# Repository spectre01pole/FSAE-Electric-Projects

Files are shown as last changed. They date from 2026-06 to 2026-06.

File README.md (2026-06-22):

# FSAE Electric Projects

Projects developed as part of Formula Student Electric vehicle development.

## Developed Circuit Boards

### Tractive System Active Light (TSAL)
- Designed and tested the TSAL board.
- Used to indicate the status of the tractive system according to Formula Student regulations.

### Voltage Indicator Board
- Designed circuitry for monitoring and indicating system voltage levels.
- Ensures safe operation and easy diagnostics.

### Brake System Plausibility Device (BSPD)
- Developed the BSPD circuit for safety compliance.
- Detects faults and disconnects power when necessary.

### Ready-To-Drive Sound Board (RTDS)
- Designed the circuit responsible for generating the Ready-To-Drive sound.
- Provides audible indication before vehicle movement.

## Skills Applied
- Analog Circuit Design
- PCB Design
- Schematic Capture
- Component Selection
- Testing and Debugging
- Electrical Safety Systems
- Formula Student EV Regulations

These projects were developed during my involvement with the Formula Student Electric team.

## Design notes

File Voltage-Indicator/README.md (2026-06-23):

# Voltage Indicator Board

## Overview

The Voltage Indicator Board is designed to provide visual indication of electrical system voltage conditions, supporting system monitoring and electrical safety awareness.

## Project Scope

This project focused on the design of the voltage indicator circuitry and PCB layout for Formula Student Electric applications.

## Responsibilities

- Circuit design
- Voltage indication circuitry development
- Component selection
- Schematic capture
- PCB layout design
- Design documentation

## Skills Demonstrated

- Analog Electronics
- PCB Design
- Voltage Monitoring Systems
- Schematic Design
- Hardware Documentation

## Current Status

Design phase completed. Manufacturing, assembly, and vehicle-level testing have not yet been performed.

## Project Context

Developed as part of Formula Student Electric vehicle development.

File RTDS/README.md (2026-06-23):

# Ready-To-Drive Sound System (RTDS)

## Overview

The Ready-To-Drive Sound System (RTDS) is a safety subsystem that generates an audible warning signal before vehicle movement, alerting nearby personnel that the vehicle is ready for operation.

## Project Scope

This project focused on the design of the RTDS circuit and PCB layout for use in a Formula Student Electric vehicle.

## Responsibilities

- Circuit design
- Audio generation circuitry development
- Component selection
- Schematic capture
- PCB layout design
- Design documentation

## Skills Demonstrated

- Electronic Circuit Design
- PCB Design
- Audio Signal Generation
- Component Selection
- Safety System Development

## Current Status

Design phase completed. Manufacturing, assembly, and vehicle-level testing have not yet been performed.

## Project Context

Developed as part of Formula Student Electric vehicle development.

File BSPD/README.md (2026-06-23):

# Brake System Plausibility Device (BSPD)

## Overview

The Brake System Plausibility Device (BSPD) is a safety subsystem used in Formula Student Electric vehicles to detect implausible driving conditions, such as simultaneous braking and acceleration requests, and initiate protective actions when required.

## Project Scope

This project focused on the design of the BSPD circuit and PCB layout to support Formula Student Electric safety requirements.

## Responsibilities

- Circuit design
- Signal monitoring circuitry development
- Component selection
- Schematic capture
- PCB layout design
- Design documentation

## Skills Demonstrated

- Analog Electronics
- Signal Conditioning
- PCB Design
- Safety System Design
- Hardware Documentation

## Current Status

Design phase completed. Manufacturing, assembly, and vehicle-level testing have not yet been performed.

## Project Context

Developed as part of Formula Student Electric vehicle development.

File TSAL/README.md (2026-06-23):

# Tractive System Active Light (TSAL)

## Overview

The Tractive System Active Light (TSAL) is a safety-critical subsystem used in Formula Student Electric vehicles to indicate the status of the tractive system and provide a visual indication of high-voltage activity.

## Project Scope

This project focused on the design of the TSAL circuit and PCB layout in accordance with Formula Student Electric requirements.

## Responsibilities

- Circuit design
- Component selection
- Schematic capture
- PCB layout design
- Design documentation

## Skills Demonstrated

- Analog Electronics
- PCB Design
- Schematic Design
- Component Selection
- Safety-Critical System Design

## Current Status

Design phase completed. Manufacturing, assembly, and vehicle-level testing have not yet been performed.

## Project Context

Developed as part of Formula Student Electric vehicle development.

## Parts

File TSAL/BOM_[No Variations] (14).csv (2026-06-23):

Line # | Name | Description | Designator | Revision ID | Revision State | Revision Status | Quantity | Manufacturer 1 | Manufacturer Part Number 1 | Manufacturer Lifecycle 1 | Supplier 1 | Supplier Part Number 1 | Supplier Unit Price 1 | Supplier Subtotal 1
 | LM2903BIDR | 36V JI.3 DUAL COMPARATOR | UGrnn, URd | CMP-04896-000007-1 | New From Design | Up to date | 2 | Texas Instruments | LM2903BIDR | Volume Production | DigiKey | 296-LM2903BIDRCT-ND | 0.26 | 0.52
 | CRCW08051K00JNEC | RES Thick Film, 1kΩ, 5%, 0.125W, 200ppm/°C, 0805 | 1K_1, 1K_2 | CMP-02407-005778-1 | New From Design | Up to date | 2 | Vishay | CRCW08051K00JNEC | Volume Production | DigiKey | 541-CRCW08051K00JNECCT-ND | 0.1 | 0.2
 | MCU08050D1004BP500 | RES 1.05K OHM 0.5% 1/5W 0805 | 1M_1, 1M_2 | CMP-02407-001361-1 | New From Design | Up to date | 2 | Vishay | MCU08050D1004BP500 | Volume Production | Mouser | 594-MCU08050D1004BP5 | 0.44 | 0.88
 | Capacitor 1µF +/-20% 10V 0402 | Chip Capacitor, 1µF +/-20%, 10V, 0402, Thickness 0.6 mm | 1uF_1, 1uF_2 | CMP-001-00063-3 | Draft | Up to date | 2 | Yageo Group | CC0402KRX5R6BB105 | Volume Production | Arrow Electronics | CC0402KRX5R6BB105 | 0.0118 | 118
 | 2K2 5% 0402(1005) | 2K2 0.063W 5% 0402 (1005 Metric) SMD | 2.2K_1, 2.2K_3 | CMP-1011-00082-1 | Released | Up to date | 2 | Yageo Group | RC0402JR-072K2L | Volume Production | Arrow Electronics | RC0402JR-072K2L | 0.0007 | 7
 | BZD27C5V1P-E3-08 | DIODE ZENER 5.1V 800MW DO219AB | 5.1V_ZD, D_4 | CMP-02541-000027-1 | New From Design | Up to date | 2 | Vishay | BZD27C5V1P-E3-08 | Volume Production | Arrow Electronics | BZD27C5V1P-E3-08 | 0.6772 | 1.3544
 | TNPW121010K0BEEN |  | 10K__9, 10K_1, 10K_2, 10K_3, 10K_3r, 10K_4, 10K_5, 10K_6, 10K_7, 10K_10, 10K_11, 10K_12, 10K_13, 10K_14, 10K_i3, 10K_rrr | CMP-2005-00857-1 | Released | Up to date | 16 | Vishay | TNPW121010K0BEEN | Volume Production | Mouser | 71-TNPW121010K0BEEN | 1.48 | 23.68
 | LM7805CT | Positive Voltage Regulator, 5 V, 1 A, -40 to 125 degC, 3-Pin TO-220, RoHS, Tube | 12V_5V_REG | CMP-2000-04938-1 | Released | Up to date | 1 | onsemi | LM7805CT | Obsolete
 | THN 20-1212 | THN 20-1212 Module DC-DC 12VIN 1-OUT 12V 1.67A 20W 6-Pin | 12V_12V_DC-DC | CMP-01539-55433698-1 | New From Design | Up to date | 1 | Traco Power | THN 20-1212 | Volume Production | DigiKey | THN20-1212-ND | 46.58 | 46.58
 | CRCW121822K0FKEK | RES Thick Film, 22kΩ, 1%, 1W, 100ppm/°C, 1218 | 22K_2 | CMP-1016-00638-2 | Unknown server | Up to date | 1 | Vishay | CRCW121822K0FKEK | Volume Production | Mouser | 71-CRCW121822K0FKEK | 0.6 | 0.6
 | 27K 1% 2010(5025) | 27K 0.75W 1% 2010 (5025 Metric) SMD | 27K_1 | CMP-1017-00670-1 | Released | Up to date | 1 | Vishay | CRCW201027K0FKTF | Volume Production | DigiKey | CRCW201027K0FKTF-ND | 0.09848 | 393.92
 | 4K7 5% 1210(3225) | 4K7 0.5W 5% 1210 (3225 Metric) SMD | 47K_n | CMP-1015-00090-1 | Released | Up to date | 1 | Vishay | CRCW12104K70JNEA | Volume Production | Arrow Electronics | CRCW12104K70JNEA | 0.0085 | 0.0085
 | 56K 5% 0805(2012) | 56K 0.125W 5% 0805 (2012 Metric) SMD | 56K_1 | CMP-1013-00116-1 | Released | Up to date | 1 | Vishay | CRCW080556K0JNEA | Volume Production | Arrow Electronics | CRCW080556K0JNEA | 0.001 | 0.001
 | CRCW121082K0FKEA | RES SMD 205K OHM 1% 1/2W 2203 | 82K_1, 82K_2 | CMP-1015-00726-2 | Unknown server | Up to date | 2 | Yageo Group | RC1210FR-0782KL | Volume Production | Mouser | 603-RC1210FR-0782KL | 0.13 | 0.26
 | TNPW0805100KDEEA |  | 100K_1, 100K_2, 100K_3, RA_100K, RB_100K | CMP-2001-04708-1 | Released | Up to date | 5 | Vishay | TNPW0805100KDEEA | Volume Production | DigiKey | 541-3911-1-ND | 0.14 | 0.7
 | C0805C104K5RACTU | CAP CER 0.1UF 50V X7R 0805 | 100nF_1, 100nF_2, 100nF_3, 100nF_4, 100nF_6, 100nF_7, 100nF_8, 100nF_9, 100nF_10, 100nF_11 | CMP-2007-00279-2 | Unknown server | Up to date | 10 | Yageo Group | C0805C104K5RACTU | Volume Production | Conrad | 3523445 | 0.01142 | 0.11424
 | Capacitor 0.1 uF +/- 5% 16 V 0402 | Chip Capacitor, 0.1 uF, +/- 5%, 16 V, 0402 (1005 Metric) | 100nF_13, 100nF_14 | CMP-001-00001-6 | Draft | Up to date | 2 | Murata | GRM155R71C104JA88D | Not Recommended for New Design | DigiKey | 490-6327-6-ND | 0.1 | 0.2
 | Capacitor 330µF +/-20% 6.3V D3 | Molded Tantalum Polymer Capacitor, 330 uF, +/- 20%, 6.3 V, -55 to 105 degC, 2-Pin SMD, RoHS, Tape and Reel | 330uF | CMP-001-00058-3 | Draft | Up to date | 1 | Panasonic | 6TPF330M9L | Volume Production | DigiKey | P16258CT-ND | 2.98 | 2.98
 | NE555DR | IC OSC SGL TIMER 100KHZ 8-SOIC | 555_1 | CMP-1685-00007-2 | Unknown server | Up to date | 1 | Texas Instruments | NE555DR | Volume Production | Arrow Electronics | NE555DR | 0.2709 | 0.2709
 | SN74LVC2G08IDCTRQ1 | Automotive Catalog Dual 2-Input Positive-AND Gate, DCT0008A, LARGE T&R | AND_1, AND_2, AND_PWR_1, AND_PWR_IC, ANDA, ANDB | CMP-0859-00543-3 | Released | Up to date | 6 | Texas Instruments | SN74LVC2G08IDCTRQ1 | Volume Production | Arrow Electronics | SN74LVC2G08IDCTRQ1 | 0.5911 | 3.5466
 | JANTX2N2222AUB/TR | JANTX2N2222AUB/TR Trans Gp Bjt NPN 50V 0.8A 3-PIN Ub T/r | BJT_1 | CMP-00252-101463705-1 | New From Design | Up to date | 1 | Microchip | JANTX2N2222AUB/TR | Volume Production | Avnet | JANTX2N2222AUB/TR | 5.7232 | 5.7232
 | CAP_2.2uF-10V-10%-0603 | 2.2µF ±10% 16V Ceramic Capacitor X5R 0603 (1608 Metric) | C_2.2uF | CMP-001-00120-1 | Draft | Up to date | 1 | Yageo Group | C0603C225K4PACTU | Volume Production | Arrow Electronics | C0603C225K4PACTU | 0.0174 | 69.6
 | 691213710003 | 213 Series 5MM Pitch Straight, Pcb Terminal Block, Through Hole, 3 Way | CMD_CONN, FB_CONN, GLVconnect, SCSnDASHind | CMP-1502-02527-3 | Released | Up to date | 4 | Wurth Elektronik | 691213710003 | Volume Production | DigiKey | 732-2039-ND | 1.43 | 5.72
 | 39-29-4069 | 39-29-4069 Conn Power HDR 6 POS 4.2mm Solder RA Thru-Hole 6 Terminal 1 Port Mini-Fit Jr™ Bag | Con B, conn A, TSconnec | CMP-00257-06821913-1 | New From Design | Up to date | 3 | Molex | 39-29-4069 | Volume Production | Arrow Electronics | 0039294069 | 3.6752 | 11.0256
 | 1N4148 | DIODE GEN PURP 100V 200MA DO35 | D2 | CMP-07163-000046-1 | New From Design | Up to date | 1 | onsemi | 1N4148 | Volume Production | Arrow Electronics | 1N4148 | 0.0045 | 0.0045
 | 1N4007 | Rectifier diode 1000 V 1 A DO-41, , | drec | CMP-123542-000001-1 | New From Design | Up to date | 1 | Diotec | 1N4007 | Volume Production | Conrad | 162272 | 0.03427 | 0.03427
 | 2N7002H6327XTSA2 | MOSFET N-CH 60V 0.3A SOT23 | M1, M2, M4 | CMP-32901-000180-1 | New From Design | Up to date | 3 | Infineon | 2N7002H6327XTSA2 | Volume Production | Arrow Electronics | 2N7002H6327XTSA2 | 0.0398 | 119.4
 | IRLML6402TRPBF | MOSFET P-CH 20V 3.7A SOT-23 | M3 | CMP-32901-000130-1 | New From Design | Up to date | 1 | Infineon | IRLML6402TRPBF | End of Life | Conrad | 162833 | 0.0914 | 0.0914
 | 9775036360R | WA-SMSR SMT Steel Spacer, Reverse M3 non Stop | MP1, MP2, MP3, MP4 | CMP-03913-78872569-2 | New From Design | Up to date | 4 | Wurth Elektronik | 9775036360R | Volume Production | DigiKey | 732-10913-1-ND | 1.09 | 4.36
 | CD4011BF3A | CMOS Quad 2-Input NAND Gate, J0014A, TUBE | NAND_PWR_IC, NOT_A, NOT_B, NOT_C, NOT_D | CMP-1627-00341-2 | Released | Up to date | 5 | Texas Instruments | CD4011BF3A | Volume Production | Arrow Electronics | CD4011BF3A | 18.53 | 685.61
 | PC817X1J000F | OPTOISOLATOR 5KV TRANS 4DIP | OP1_1, OPT_2 | CMP-65434-000003-1 | New From Design | Up to date | 2 | Sharp | PC817X1J000F | Obsolete
 | CD4071BPWR | CMOS Quad 2-Input OR Gate, PW0014A, LARGE T&R | OR_PWR_IC, ORA, ORB, ORC, ORRD | CMP-1573-00201-3 | Released | Up to date | 5 | Texas Instruments | CD4071BPWR | Not Recommended for New Design | DigiKey | 296-24349-1-ND | 0.8 | 4
 | MC14044BDG | MC14044BDG 4044 Tube 4000B ACTIVE (Last Updated: 5days ago) latch circuit 350ns 8.8mA 8.8mA 175ns 1.5mm | SR_Ltch | CMP-00278-00853159-1 | New From Design | Up to date | 1 | onsemi | MC14044BDG | Volume Production | Arrow Electronics | MC14044BDG | 0.3195 | 15.336
 | SN74LV86ATPWRG4Q1 | Automotive Catalog Quadruple 2-Input Exclusive-OR Gates, PW0014A, LARGE T&R | XOR_PWR_IC, XORA, XORB, XORC, XORD | CMP-0778-00153-3 | Released | Up to date | 5 | Texas Instruments | SN74LV86ATPWRG4Q1 | Volume Production | DigiKey | 296-SN74LV86ATPWRG4Q1CT-ND | 0.8 | 4

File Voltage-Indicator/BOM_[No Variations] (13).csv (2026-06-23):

Line # | Name | Description | Designator | Revision ID | Revision Status | Quantity | Manufacturer 1 | Manufacturer Part Number 1 | Manufacturer Lifecycle 1 | Supplier 1 | Supplier Part Number 1 | Supplier Unit Price 1 | Supplier Subtotal 1
 | CRCW08051K00JNEC | RES Thick Film, 1kΩ, 5%, 0.125W, 200ppm/°C, 0805 | 1K_1 | CMP-02407-005778-1 | Up to date | 1 | Vishay | CRCW08051K00JNEC | Volume Production | Mouser | 71-CRCW08051K00JNEC | 0.1 | 0.1
 | MCU08050D1004BP500 | RES 1.05K OHM 0.5% 1/5W 0805 | 1M_1 | CMP-02407-001361-1 | Up to date | 1 | Vishay | MCU08050D1004BP500 | Volume Production
 | 4K7 5% 1210(3225) | 4K7 0.5W 5% 1210 (3225 Metric) SMD | 4.7K | CMP-1015-00090-1 | Up to date | 1 | Vishay | CRCW12104K70JNEA | Volume Production | Arrow Electronics | CRCW12104K70JNEA | 0.0085 | 0.0085
 | BZD27C5V1P-E3-08 | DIODE ZENER 5.1V 800MW DO219AB | 5.1V_ZD | CMP-02541-000027-1 | Up to date | 1 | Vishay | BZD27C5V1P-E3-08 | Volume Production | Arrow Electronics | BZD27C5V1P-E3-08 | 0.6772 | 0.6772
 | TNPW121010K0BEEN |  | 10K_1, 10K_2, 10K_3 | CMP-2005-00857-1 | Up to date | 3 | Vishay | TNPW121010K0BEEN | Volume Production | Mouser | 71-TNPW121010K0BEEN | 1.78 | 5.34
 | 45K3 1% 2512(6432) | 45K3 1W 1% 2512 (6432 Metric) SMD | 45.3K | CMP-1018-00697-1 | Up to date | 1 | Vishay | CRCW251245K3FKEG | Volume Production | Mouser | 71-CRCW251245K3FKEG | 0.42 | 0.42
 | CRCW121082K0FKEA | RES SMD 205K OHM 1% 1/2W 2203 | 82K_1 | CMP-1015-00726-2 | Up to date | 1 | Yageo Group | RC1210FR-0782KL | Volume Production | Mouser | 603-RC1210FR-0782KL | 0.13 | 0.13
 | TNPW0805100KDEEA |  | 100K_1, 100K_2 | CMP-2001-04708-1 | Up to date | 2 | Vishay | TNPW0805100KDEEA | Volume Production | Mouser | 71-TNPW0805100KDEEA | 0.14 | 0.28
 | C0805C104K5RACTU | CAP CER 0.1UF 50V X7R 0805 | 100nF_1, 100nF_2 | CMP-2007-00279-2 | Up to date | 2 | Yageo Group | C0805C104K5RACTU | Volume Production | RS (Formerly Allied Electronics) | C0805C104K5RACTU | 0.02 | 0.04
 | 220R 1% 2010(5025) | 220R 0.75W 1% 2010 (5025 Metric) SMD | 220Ohm | CMP-1017-00433-1 | Up to date | 1 | Vishay | CRCW2010220RFKEF | Volume Production | Mouser | 71-CRCW2010220RFKEF | 0.3 | 0.3
 | LM2903BIDR | 36V JI.3 DUAL COMPARATOR | CompUHVin | CMP-04896-000007-1 | Up to date | 1 | Texas Instruments | LM2903BIDR | Volume Production | Mouser | 595-LM2903BIDR | 0.26 | 0.26
 | 2N7002H6327XTSA2 | MOSFET N-CH 60V 0.3A SOT23 | M2 | CMP-32901-000180-1 | Up to date | 1 | Infineon | 2N7002H6327XTSA2 | Volume Production | Newark | 2N7002H6327XTSA2 | 0.292 | 0.292
 | 2N3904BU | NPN General-Purpose Amplifier, 40 V VCEO, 0.2 A, -55 to 150 degC, 2-Pin TO-92, RoHS, Bulk | QP1 | CMP-2000-04944-1 | Up to date | 1 | onsemi | 2N3904BU | Volume Production | Avnet | 2N3904BU | 0.18551 | 0.18551
 | BC557BTF | BC557BTF Small Signal Bipolar Transistor, 0.1A I(C), 45V V(BR)CEO, 1-Element, PNP, Silicon, TO-92 | QP2 | CMP-00278-84408945-1 | Up to date | 1 | onsemi | BC557BTF | Volume Production | Mouser | 512-BC557BTF | 0.28 | 0.28
 | Resistor 1K +/-5 % 0402 63 mW | Chip Resistor, 1 kOhms, +/-5 %, 63 mW, -55 to 155 degC, 0402 | 1K | CMP-009-00157-3 | Up to date | 1 | Bourns | CR0402-JW-102GLF | Volume Production | Arrow Electronics | CR0402-JW-102GLF | 0.0014 | 112
 | 691213710003 | 213 Series 5MM Pitch Straight, Pcb Terminal Block, Through Hole, 3 Way | HVbuckLV connect, TSconnect | CMP-1502-02527-3 | Up to date | 2 | Wurth Elektronik | 691213710003 | Volume Production | Mouser | 710-691213710003 | 1.5 | 3
 | 39-29-4069 | 39-29-4069 Conn Power HDR 6 POS 4.2mm Solder RA Thru-Hole 6 Terminal 1 Port Mini-Fit Jr™ Bag | REDconnect | CMP-00257-06821913-1 | Up to date | 1 | Molex | 39-29-4069 | Volume Production | Arrow Electronics | 0039294069 | 3.6752 | 3.6752

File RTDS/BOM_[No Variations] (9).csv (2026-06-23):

Line # | Name | Description | Designator | Revision ID | Revision Status | Quantity | Manufacturer 1 | Manufacturer Part Number 1 | Manufacturer Lifecycle 1 | Supplier 1 | Supplier Part Number 1 | Supplier Unit Price 1 | Supplier Subtotal 1
 | Resistor 1K +/-5 % 0402 63 mW | Chip Resistor, 1 kOhms, +/-5 %, 63 mW, -55 to 155 degC, 0402 | 1K_base | CMP-009-00157-3 | Up to date | 1 | Vishay | CRCW04021K00JNED | Volume Production | Newark | CRCW04021K00JNED | 0.002 | 0.002
 | Capacitor 1µF +/-20% 10V 0402 | Chip Capacitor, 1µF +/-20%, 10V, 0402, Thickness 0.6 mm | 1uF_conv | CMP-001-00063-3 | Up to date | 1 | Yageo Group | CC0402KRX5R6BB105 | Volume Production | Mouser | 603-CC402KRX5R6BB105 | 0.11 | 0.11
 | 4K7 5% 1210(3225) | 4K7 0.5W 5% 1210 (3225 Metric) SMD | 4.7k | CMP-1015-00090-1 | Up to date | 1 | Vishay | CRCW12104K70JNEA | Volume Production | Arrow Electronics | CRCW12104K70JNEA | 0.0085 | 0.0085
 | TNPW040210K0DEED |  | 10K, 10K_2 | CMP-2002-01682-1 | Up to date | 2 | Vishay | TNPW040210K0DEED | Volume Production
 | Capacitor 0.1 uF +/- 5% 16 V 0402 | Chip Capacitor, 0.1 uF, +/- 5%, 16 V, 0402 (1005 Metric) | 100nF, 100nF_2 | CMP-001-00001-6 | Up to date | 2 | Murata | GRM155R71C104JA88D | Not Recommended for New Design | DigiKey | 490-6327-1-ND | 0.1 | 0.2
 | Capacitor 330µF +/-20% 6.3V D3 | Molded Tantalum Polymer Capacitor, 330 uF, +/- 20%, 6.3 V, -55 to 105 degC, 2-Pin SMD, RoHS, Tape and Reel | 330uF | CMP-001-00058-3 | Up to date | 1 | Panasonic | 6TPF330M9L | Volume Production | DigiKey | P16258CT-ND | 2.98 | 2.98
 | GRT31C5C1E104FA02L | Multi-Layer Ceramic Capacitor 100nF 25V C0G ±1% 1206 Emboss T/R | C1_100nF | CMP-06035-026891-1 | Up to date | 1 | Murata | GRT31C5C1E104FA02L | Volume Production | Mouser | 81-GRT31C5C1E104FA2L | 0.99 | 0.99
 | CAP_1uF-16V-10%-0201 | 1µF ±20% 16V Ceramic Capacitor X5R 0201 (0603 Metric) | C2_1uF | CMP-001-00116-1 | Up to date | 1 | Samsung Electro-Mechanics | CL03A105MO3NRNH | Volume Production | DigiKey | 1276-6798-1-ND | 0.22 | 0.22
 | BZD27C5V1P-E3-08 | DIODE ZENER 5.1V 800MW DO219AB | Drect | CMP-02541-000027-1 | Up to date | 1 | Vishay | BZD27C5V1P-E3-08 | Volume Production | Newark | BZD27C5V1P-E3-08 | 0.749 | 3.745
 | 90136-2106 | CONN HEADER R/A 6POS 2.54MM | InputConnector | CMP-04776-000069-1 | Up to date | 1 | Molex | 90136-2106 | Volume Production | Newark | 90136-2106 | 0.153 | 0.153
 | 22-04-1021 | KK Mini-Latch Straight Male, PCB Header, Through Hole, 1 Rows, 2 Contacts, 2.5mm Pitch | RTDinput, SpeakerOutput | CMP-04776-000257-2 | Up to date | 2 | Molex | 22-04-1021 | Volume Production | RS (Formerly Allied Electronics) | 22-04-1021 | 0.09 | 0.18
 | 2N2222 | Low Power Bipolar NPN Transistor, 30 V, -65 to 200 degC, 3-Pin TO-18, RoHS, Bulk | NPN | CMP-2000-05237-1 | Up to date | 1 | Multicomp | 2N2222 | Volume Production | Newark | 2N2222 | 0.725 | 0.725
 | LM7805CT | Positive Voltage Regulator, 5 V, 1 A, -40 to 125 degC, 3-Pin TO-220, RoHS, Tube | 5VREG | CMP-2000-04938-1 | Up to date | 1 | onsemi | LM7805CT | Obsolete
 | ATTINY85V-10SHR | ATTINY85V-10SHR 8-bit Microcontrollers - MCU 10MHz, EIAJ SOIC Ind Temp, Green T&R | ATtinyMC | CMP-00252-77762337-1 | Up to date | 1 | Microchip | ATTINY85V-10SHR | Volume Production

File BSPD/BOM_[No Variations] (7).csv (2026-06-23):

Line # | Name | Description | Designator | Revision ID | Revision Status | Quantity | Manufacturer 1 | Manufacturer Part Number 1 | Manufacturer Lifecycle 1 | Supplier 1 | Supplier Part Number 1 | Supplier Unit Price 1 | Supplier Subtotal 1
 | TNPW040210K0DEED, 10 |  | 10K, 10K_1, 10k_2, 10k_3, 10k_4, 10k_6, 10k_7, 10k_8, 10K_9, 10K_10 | CMP-2002-01682-1 | Up to date | 10 | Vishay | TNPW040210K0DEED | Volume Production
 | 3290W-1-203 |  | 20k, 20k_1 | CMP-2000-05581-2 | Up to date | 2 | Bourns | 3290W-1-203 | Volume Production | Arrow Electronics | 3290W-1-203 | 0 | 0
 | 100K 1% 0603(1608) | 100K 0.1W 1% 0603 (1608 Metric) SMD | 100K, 100K_1, 100k_2, 100k_3, 100k_4 | CMP-1012-00736-1 | Up to date | 5 | Vishay | CRCW0603100KFKEC | Volume Production | Arrow Electronics | CRCW0603100KFKEC | 0.0005 | 0.0025
 | AC1210KKX7R0BB104 | CAP CER 0.1UF 100V X7R 1210 | 100nF, 100nF_2, 100nF_4 | CMP-03422-000642-1 | Up to date | 3 | Yageo Group | AC1210KKX7R0BB104 | Volume Production | Newark | AC1210KKX7R0BB104 | 0.186 | 0.558
 | 824032815 | Tvs Diode, Bidir, 5V, Dfn1610 Rohs Compliant: Yes | D1_TVS, D2_TVS | CMP-03913-133963841-2 | Up to date | 2 | Wurth Elektronik | 824032815 | Volume Production | Newark | 824032815 | 1.45 | 2.9
 | LM393D | IC VOLT COMPARATOR DUAL LP 8SOIC | U_1, U2, U4 | CMP-12132-000003-1 | Up to date | 3 | STMicroelectronics | LM393D | Volume Production | Avnet | LM393D | 0.21158 | 0.63474
 | SN74AHC1G02DCKR | Single 2-Input Positive-NOR Gate, DCK0005A, LARGE T&R | U3 | CMP-0859-00418-3 | Up to date | 1 | Texas Instruments | SN74AHC1G02DCKR | Volume Production | Mouser | 595-SN74AHC1G02DCKR | 0.1 | 0.1
 | RN73C1E100RBTDF | Res Thin Film 0402 100Ω 0.1% 1/16W 10ppm/°C Molded SMD | 100R, 100R_1 | CMP-2002-03415-2 | Up to date | 2 | TE Connectivity | RN73C1E100RBTDF | Volume Production | Mouser | 279-RN73C1E100RBTDF | 0.72 | 1.44
 | CRCW020139K0JNED |  | 39K, 39K_1 | CMP-2004-00545-1 | Up to date | 2 | Vishay | CRCW020139K0JNED | Volume Production | Mouser | 71-CRCW020139K0JNED | 0.24 | 0.48
 | MCU08050D1004BP500 | RES 1.05K OHM 0.5% 1/5W 0805 | 1M | CMP-02407-001361-1 | Up to date | 1 | Vishay | MCU08050D1004BP500 | Volume Production
 | Capacitor 10µF +/-40% 6.3V 0402 | Chip Capacitor, 10µF +/-40%, 6.3V, 0402, Thickness 0.6 mm | 10uF, C, C_2, C1 | CMP-001-00074-3 | Up to date | 4 | Murata | GRM155R60J106ME15D | Volume Production | Mouser | 81-GRM155R60J106ME5D | 0.062 | 0.62
 | Capacitor 100nF +/-20% 25V 0402 | Chip Capacitor, 100nF +/-20%, 25V, 0402, Thickness 0.6 mm | 100nF_1, 100nF_3, 100nF_5, 100nF_6 | CMP-001-00065-4 | Up to date | 4 | Yageo Group | CC0402KRX5R8BB104 | Volume Production | Arrow Electronics | CC0402KRX5R8BB104 | 0.0013 | 0.0052
 | 820K 5% 1206(3216) | 820K 0.25W 5% 1206 (3216 Metric) SMD | 820K | CMP-1014-00144-1 | Up to date | 1 | Yageo Group | RC1206JR-07820KL | Volume Production | Mouser | 603-RC1206JR-07820KL | 0.1 | 0.1
 | BSS138 | MOSFET N-CH 50V 220MA SOT-23 | Q1, Q2 | CMP-07173-000101-1 | Up to date | 2 | onsemi | BSS138 | Volume Production | Mouser | 512-BSS138 | 0.31 | 0.62
 | SI2319CDS-T1-GE3 | P-Channel (D-S) MOSFET, 40 V, -55 to 150 degC, 3-Pin SOT23 (TO-236), RoHS, Tape and Reel | Q3 | CMP-2000-07053-1 | Up to date | 1 | Vishay | SI2319CDS-T1-GE3 | Not Recommended for New Design | Mouser | 781-SI2319CDS-T1-GE3 | 1.08 | 1.08
 | MF-MSMF110/24X | PTC Resettable Fuse, 24 V, 20 A, -40 to 85 degC, 2-Pin SMD, RoHS, Tape and Reel | 1.2A / 2.2A | CMP-005-00008-3 | Up to date | 1 | Bourns | MF-MSMF110/24X | Volume Production
 | AP2012EC | LED RED CLEAR SMD | D1 | CMP-44529-000070-1 | Up to date | 1 | Kingbright | AP2012EC | Volume Production | Mouser | 604-AP2012EC | 0.23 | 0.23
 | 1N4148 | DIODE GEN PURP 100V 200MA DO35 | D2 | CMP-07163-000046-1 | Up to date | 1 | onsemi | 1N4148 | Volume Production | Arrow Electronics | 1N4148 | 0.0045 | 0.0045
 | 824551121 | TVS diode [Würth Elektronik] 824551121 TVS diode | D5 | CMP-03913-71101758-2 | Up to date | 1 | Wurth Elektronik | 824551121 | Volume Production | Mouser | 710-824551121 | 1.71 | 1.71
 | WP934CB/GD | Right Angle LED Indicator, 62.5 mW, 25 mA, -40 to 85 degC, 2-Pin THD, RoHS, Bulk | DG1 | CMP-2000-07417-1 | Up to date | 1 | Kingbright | WP934CB/GD | Volume Production | Mouser | 604-WP934CB/GD | 0.53 | 0.53
 | BM06B-ZESS-TBT(LF)(SN) | CONN HEADER SMD 6POS 1.5MM | J1 | CMP-17439-000569-1 | Up to date | 1 | JST | BM06B-ZESS-TBT(LF)(SN) | Volume Production | Mouser | 306-BM06BZESSTBTLFSN | 0.85 | 0.85
 | ALZ11B12 | LZ Relays, 12 V Coil Voltage, 400 mW Nominal Operating Power, -40 to 85 degC, 8-Pin LZ, Carton, Case, RoHS | K1 | CMP-1503-00243-1 | Up to date | 1 | Panasonic | ALZ11B12 | Volume Production
 | 200R2J | 200R 0.063W 5% 0402 (1005 Metric) SMD | R1 | CMP-009-00079-2 | Up to date | 1
 | LM1117IMP-5.0-NOPB | Low-Dropout Linear Regulator, 800 mA, -40 to 125 degC, 4-Pin SOT-223 (DCY), Green (RoHS & no Sb/Br), Tape and Reel | U1 | CMP-019-00021-3 | Up to date | 1
 | 5003 | Test Point, Orange, Height 4.6 mm, Tail Length 3 mm, 1-Pin THD, RoHS | TP1, TP2, TP9, TP10, TP11, TP12, TP17, TP18, TP22, TP23, TP24, TP25 | CMP-002-00037-2 | Up to date | 12 | Keystone | 5003 | Volume Production | DigiKey | 36-5003-ND | 0.224 | 2.688
 | 9775036360R | WA-SMSR SMT Steel Spacer, Reverse M3 non Stop | MP1, MP2, MP3, MP4 | CMP-03913-78872569-2 | Up to date | 4 | Wurth Elektronik | 9775036360R | Volume Production | Mouser | 710-9775036360R | 1.09 | 4.36

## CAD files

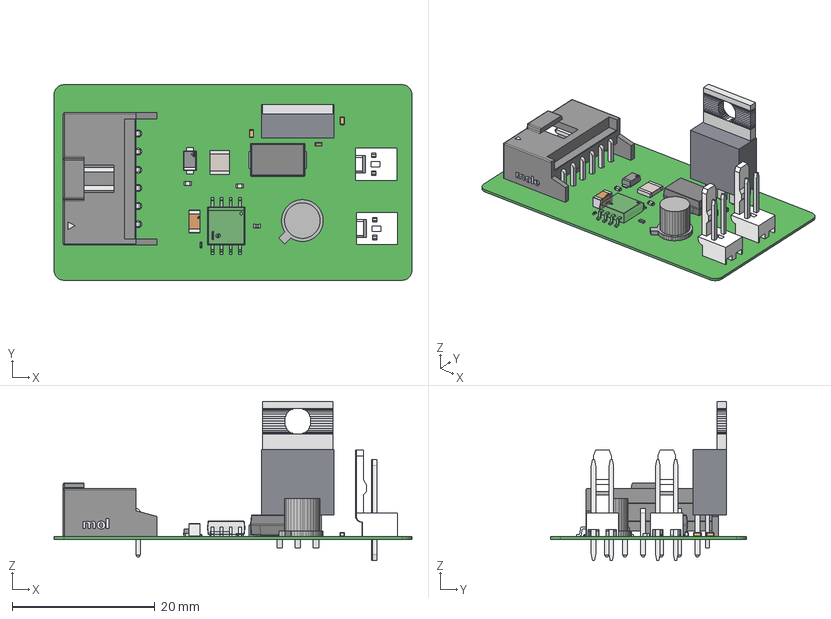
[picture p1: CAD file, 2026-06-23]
RTDS/STEP_[No Variations] for RTDS_ACTUAL.PcbDoc (1).step
50.2 x 27.4 x 22.3 mm
Molex Logo x 3
Extruded x 52
terminal
logo
User Library-User Library-0201_Cap
side x 2
Murata
IC_BODY
circle
IC_LEG x 4
Microchip logo
microchip
IC_LEG_MIR11 x 4
Lead x 2
CAPC1005X60N EIA 0402
RES0402

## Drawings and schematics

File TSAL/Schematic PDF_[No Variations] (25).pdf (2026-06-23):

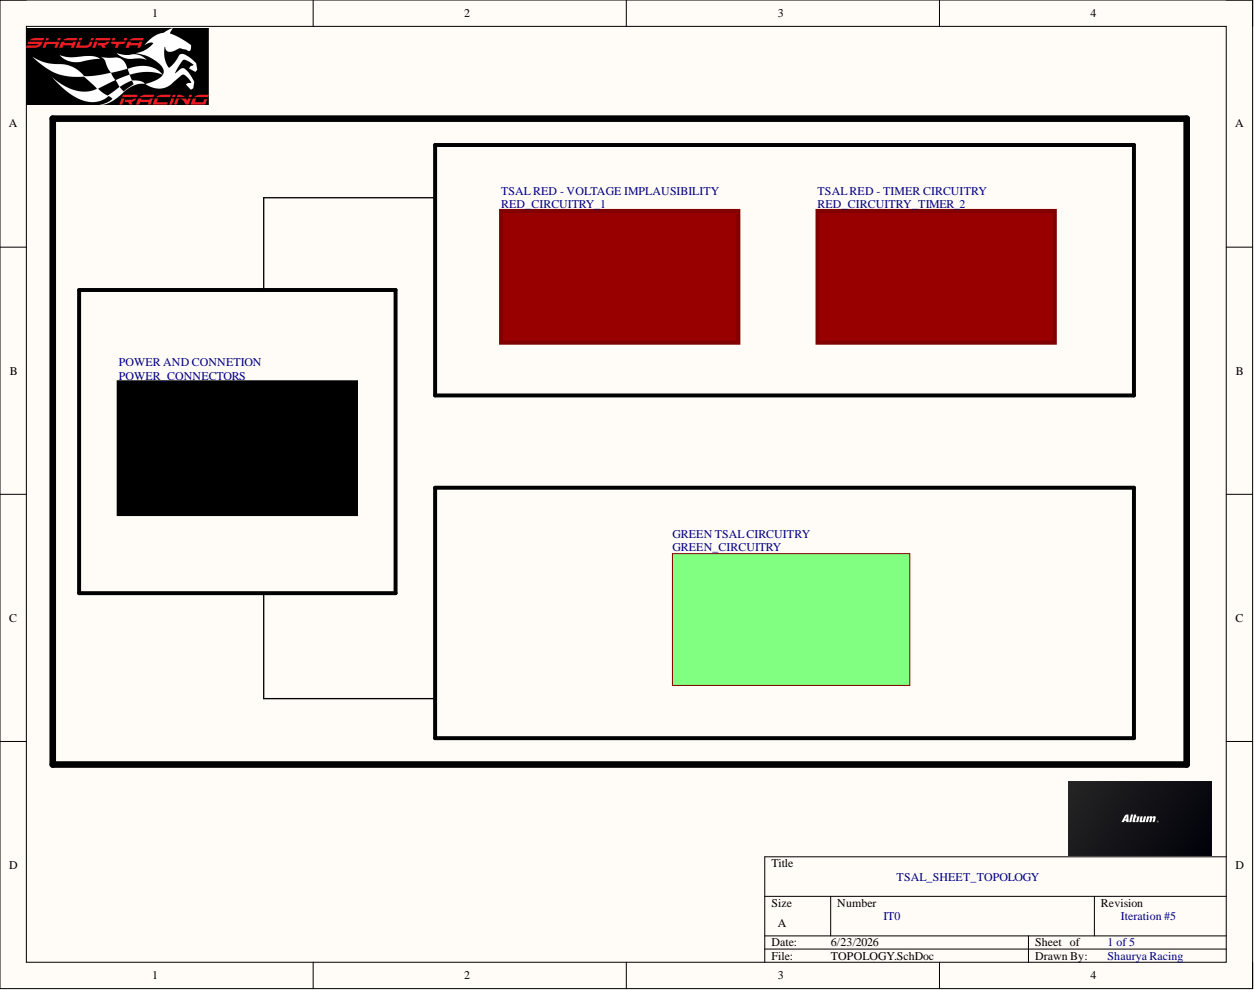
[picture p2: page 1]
Date:; Sheet of; File:; TOPOLOGY.SchDoc; Drawn By:; Iteration #5; Shaurya Racing; GREEN TSALCIRCUITRY

TSAL RED - VOLTAGE IMPLAUSIBILITY
RED_CIRCUITRY_1

TSAL RED - TIMER CIRCUITRY
RED_CIRCUITRY_TIMER_2

POWER AND CONNETION
POWER_CONNECTORS

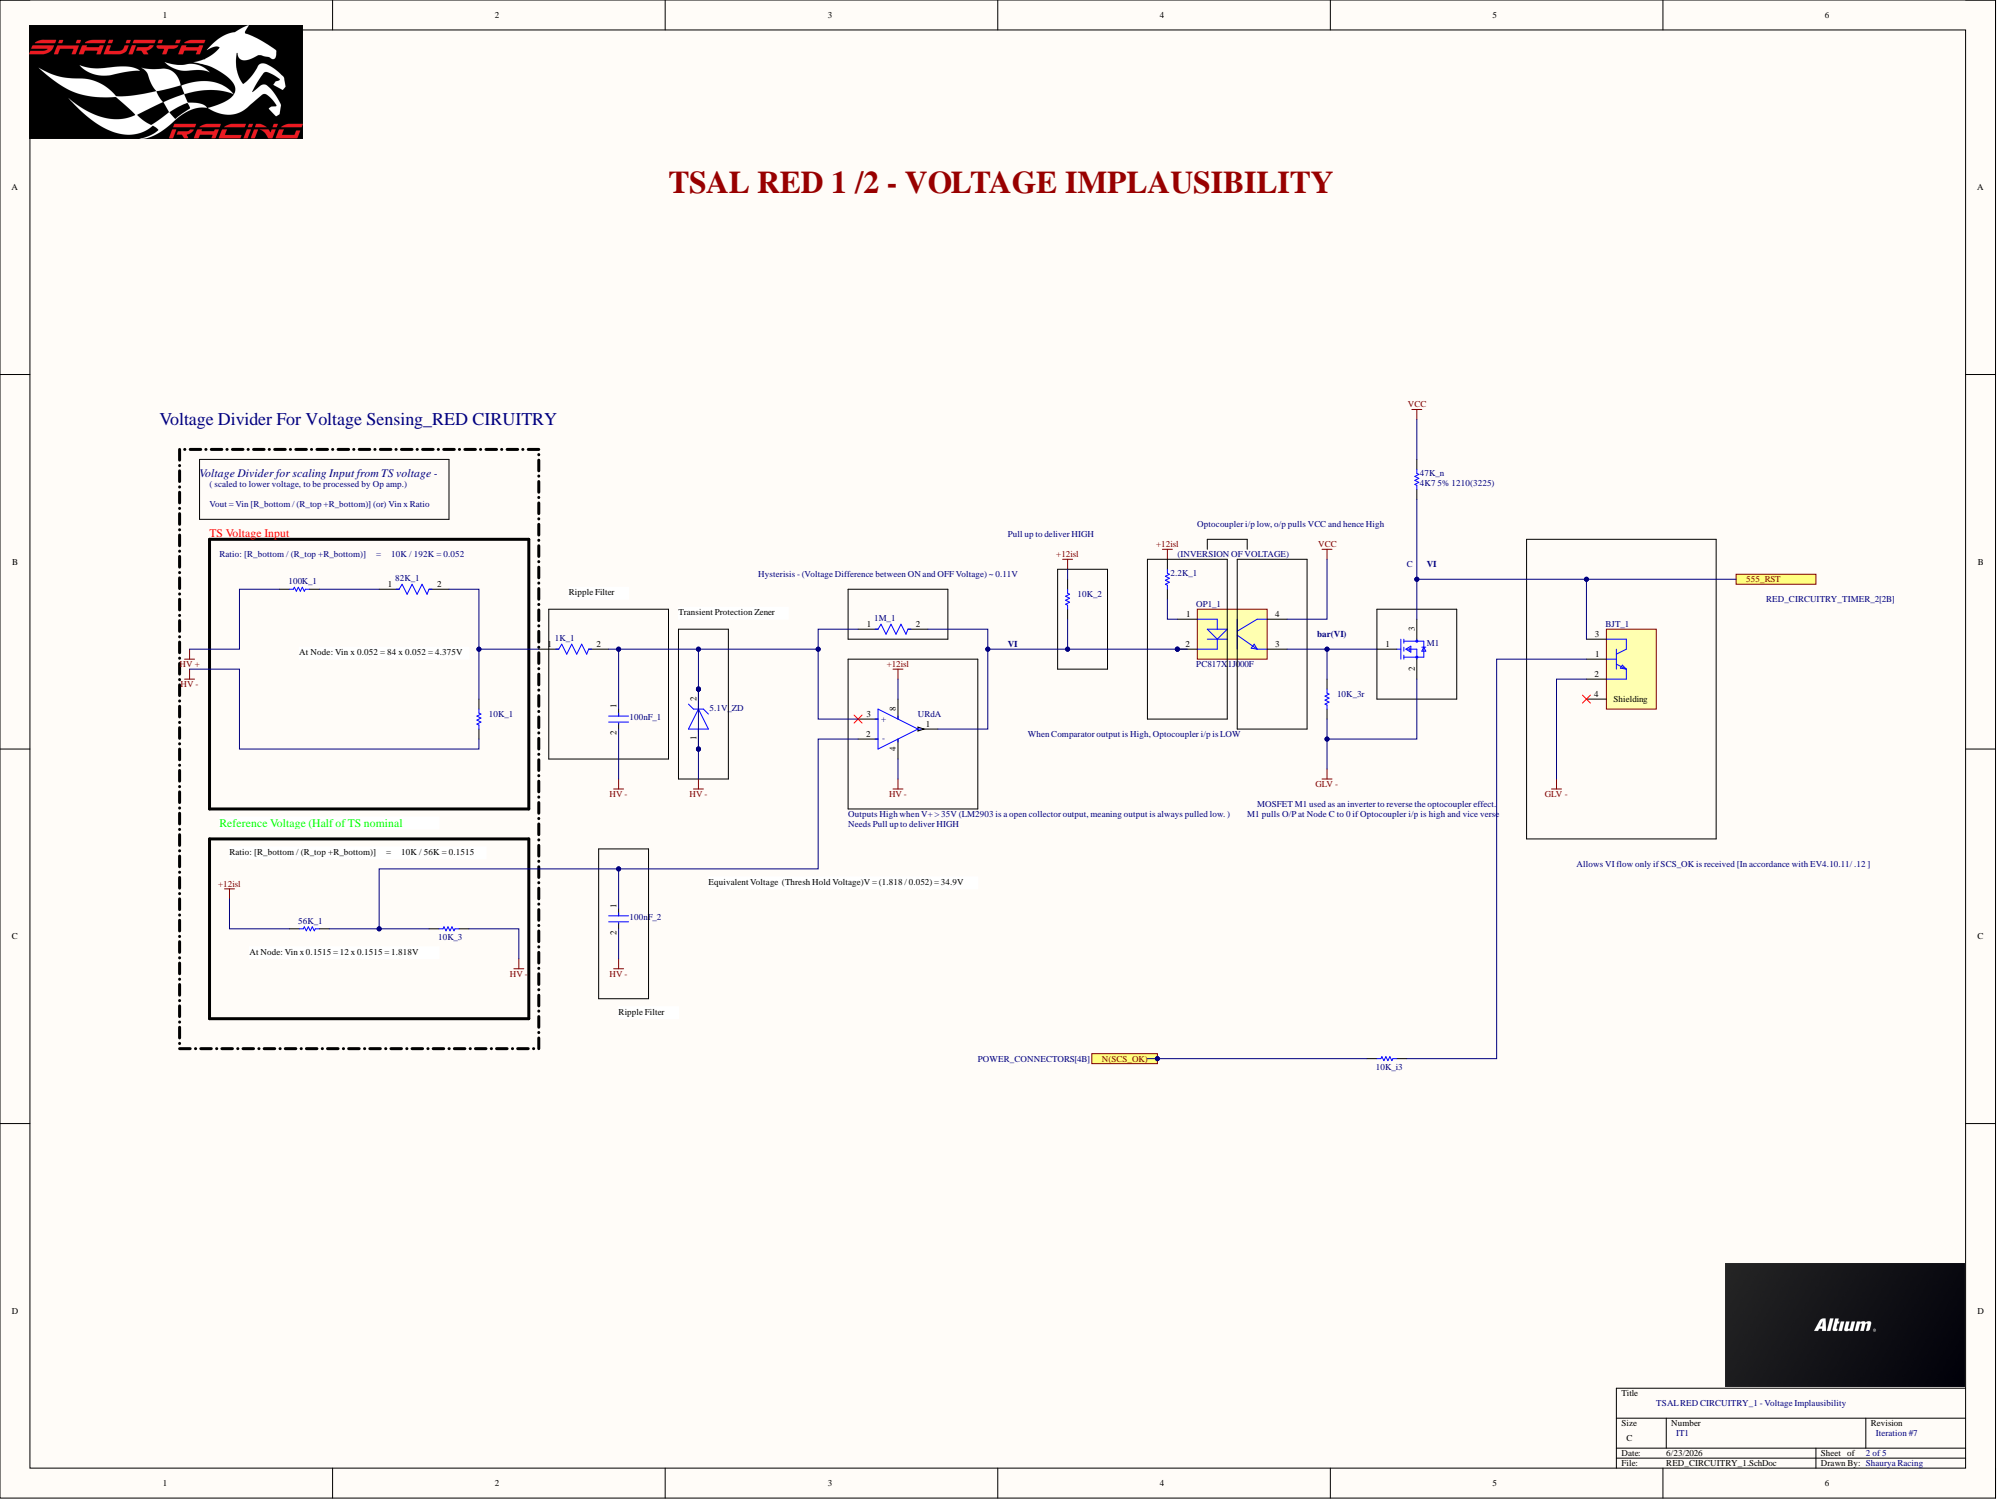
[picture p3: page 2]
File:; RED_CIRCUITRY_1.SchDoc; Drawn By:; GLV -; Shielding 4; 10K_i3 POWER_CONNECTORS[4B]; N(SCS_OK); Ratio: [R_bottom / (R_top +R_bottom)]; Ripple Filter; Iteration #7

TSAL RED 1 /2 - VOLTAGE IMPLAUSIBILITY

Voltage Divider For Voltage Sensing_RED CIRUITRY

Voltage Divider for scaling Input from TS voltage - ( scaled to lower voltage, to be processed by Op amp.)

Vout = Vin [R_bottom / (R_top +R_bottom)] (or) Vin x Ratio

Optocoupler i/p low, o/p pulls VCC and hence High

TS Voltage Input

Pull up to deliver HIGH

(INVERSION OF VOLTAGE)

Ratio: [R_bottom / (R_top +R_bottom)] | = 10K / 192K = 0.052 1 2 82K_1 100K_1

Hysterisis - (Voltage Difference between ON and OFF Voltage) ~ 0.11V

Transient Protection Zener

At Node: Vin x 0.052 = 84 x 0.052 = 4.375V

When Comparator output is High, Optocoupler i/p is LOW

MOSFET M1 used as an inverter to reverse the optocoupler effect.
M1 pulls O/P at Node C to 0 if Optocoupler i/p is high and vice verse

Outputs High when V+ > 35V (LM2903 is a open collector output, meaning output is always pulled low. )
Needs Pull up to deliver HIGH

Reference Voltage (Half of TS nominal

Allows VI flow only if SCS_OK is received [In accordance with EV4.10.11/ .12 ]

Equivalent Voltage (Thresh Hold Voltage)V = (1.818 / 0.052) = 34.9V

At Node: Vin x 0.1515 = 12 x 0.1515 = 1.818V

TSALRED CIRCUITRY_1 - Voltage Implausibility

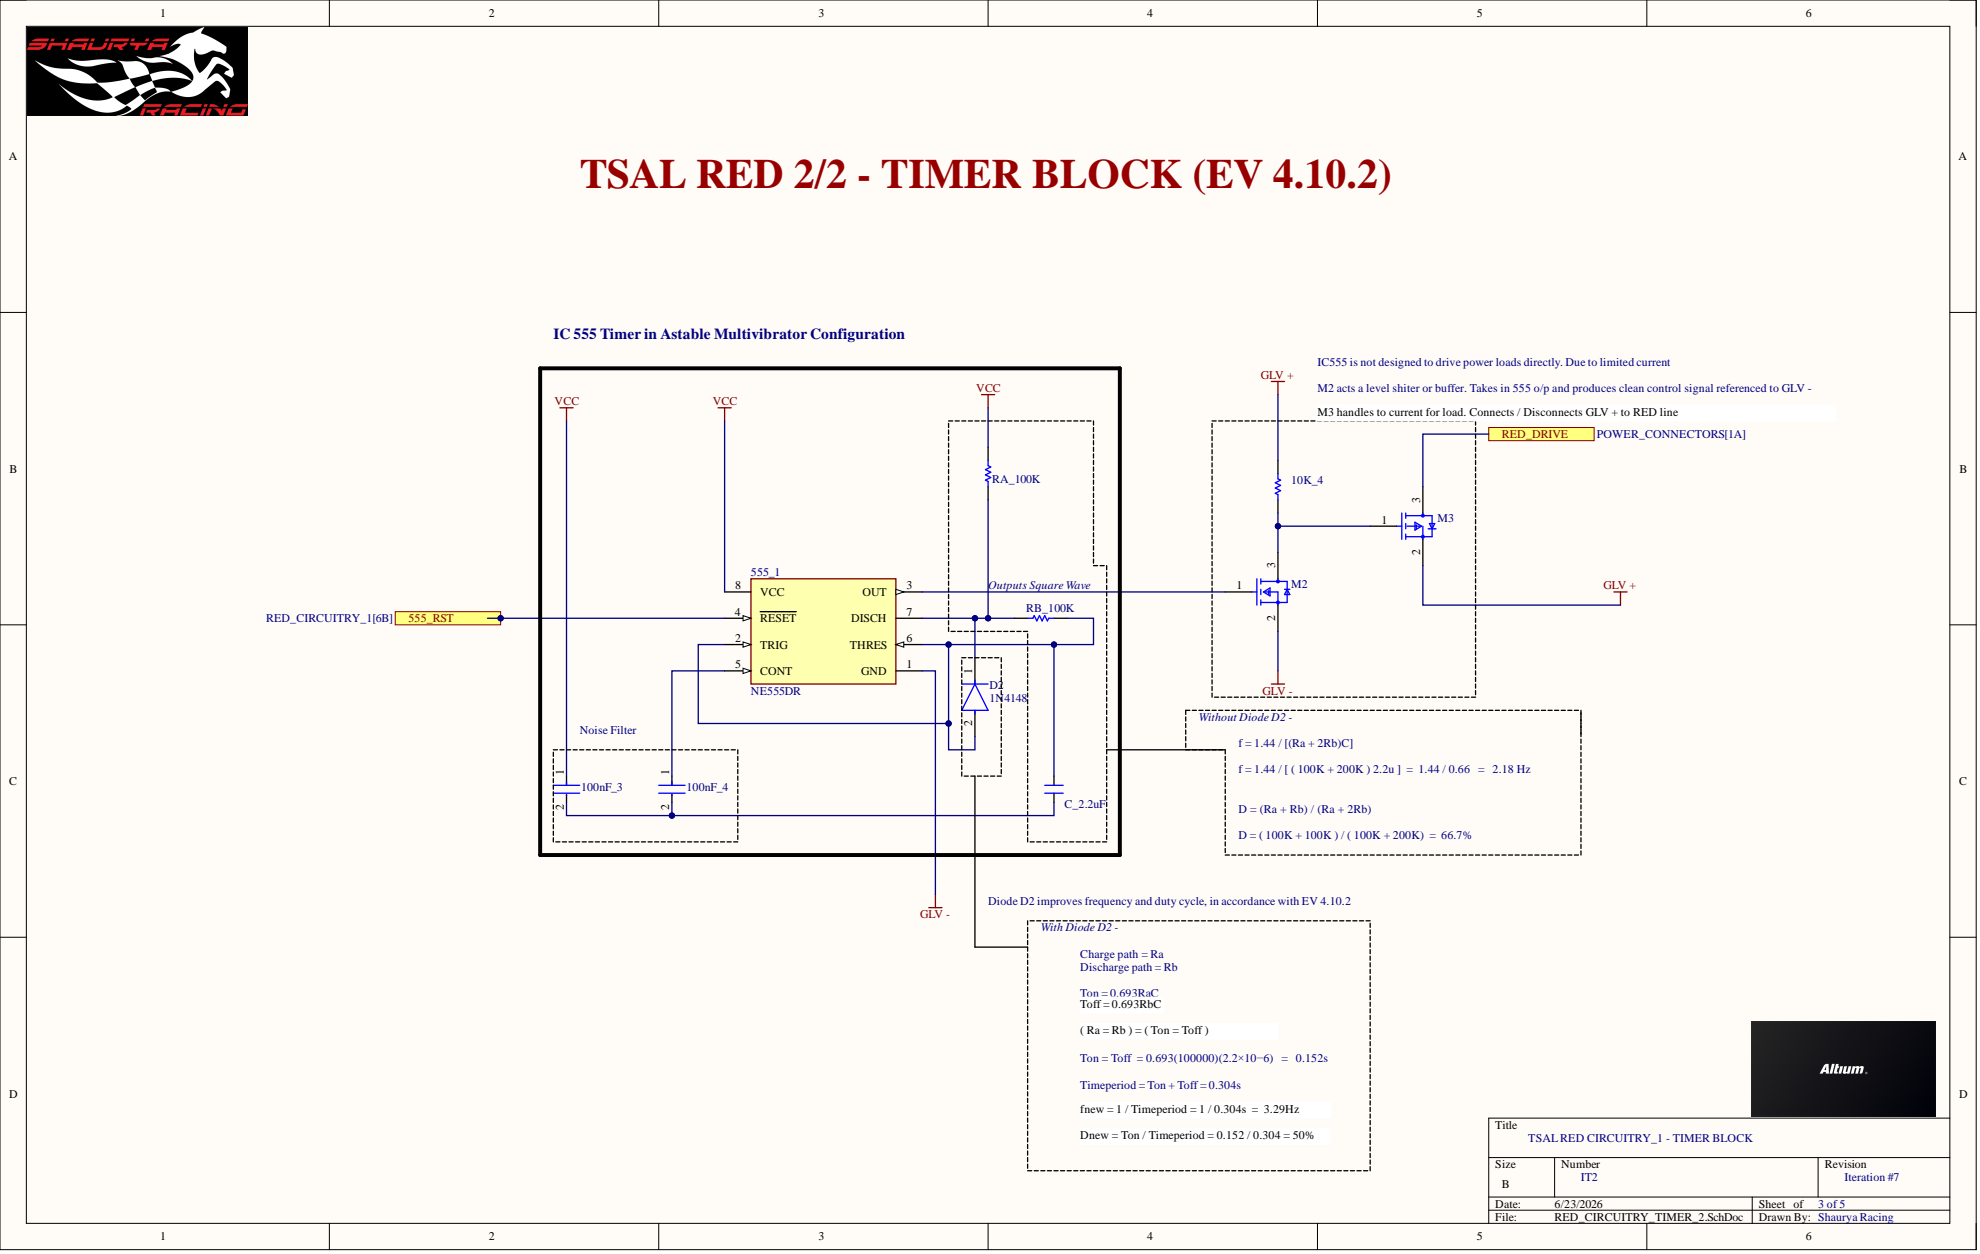
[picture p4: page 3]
r in Asta; ble Multivib; n = Toff =; Toff =; fnew =; new =; ves freq; uency an; y cycle,; n accordance; ted curren; M2 act; nal referenced; o curren; t for; oad. Co; D CIRCUIT; TIMER BL; Shaurya Raci

TSAL RED 2/2 - TIMER BLOCK (EV 4.10.2)

VCC

uces clean co

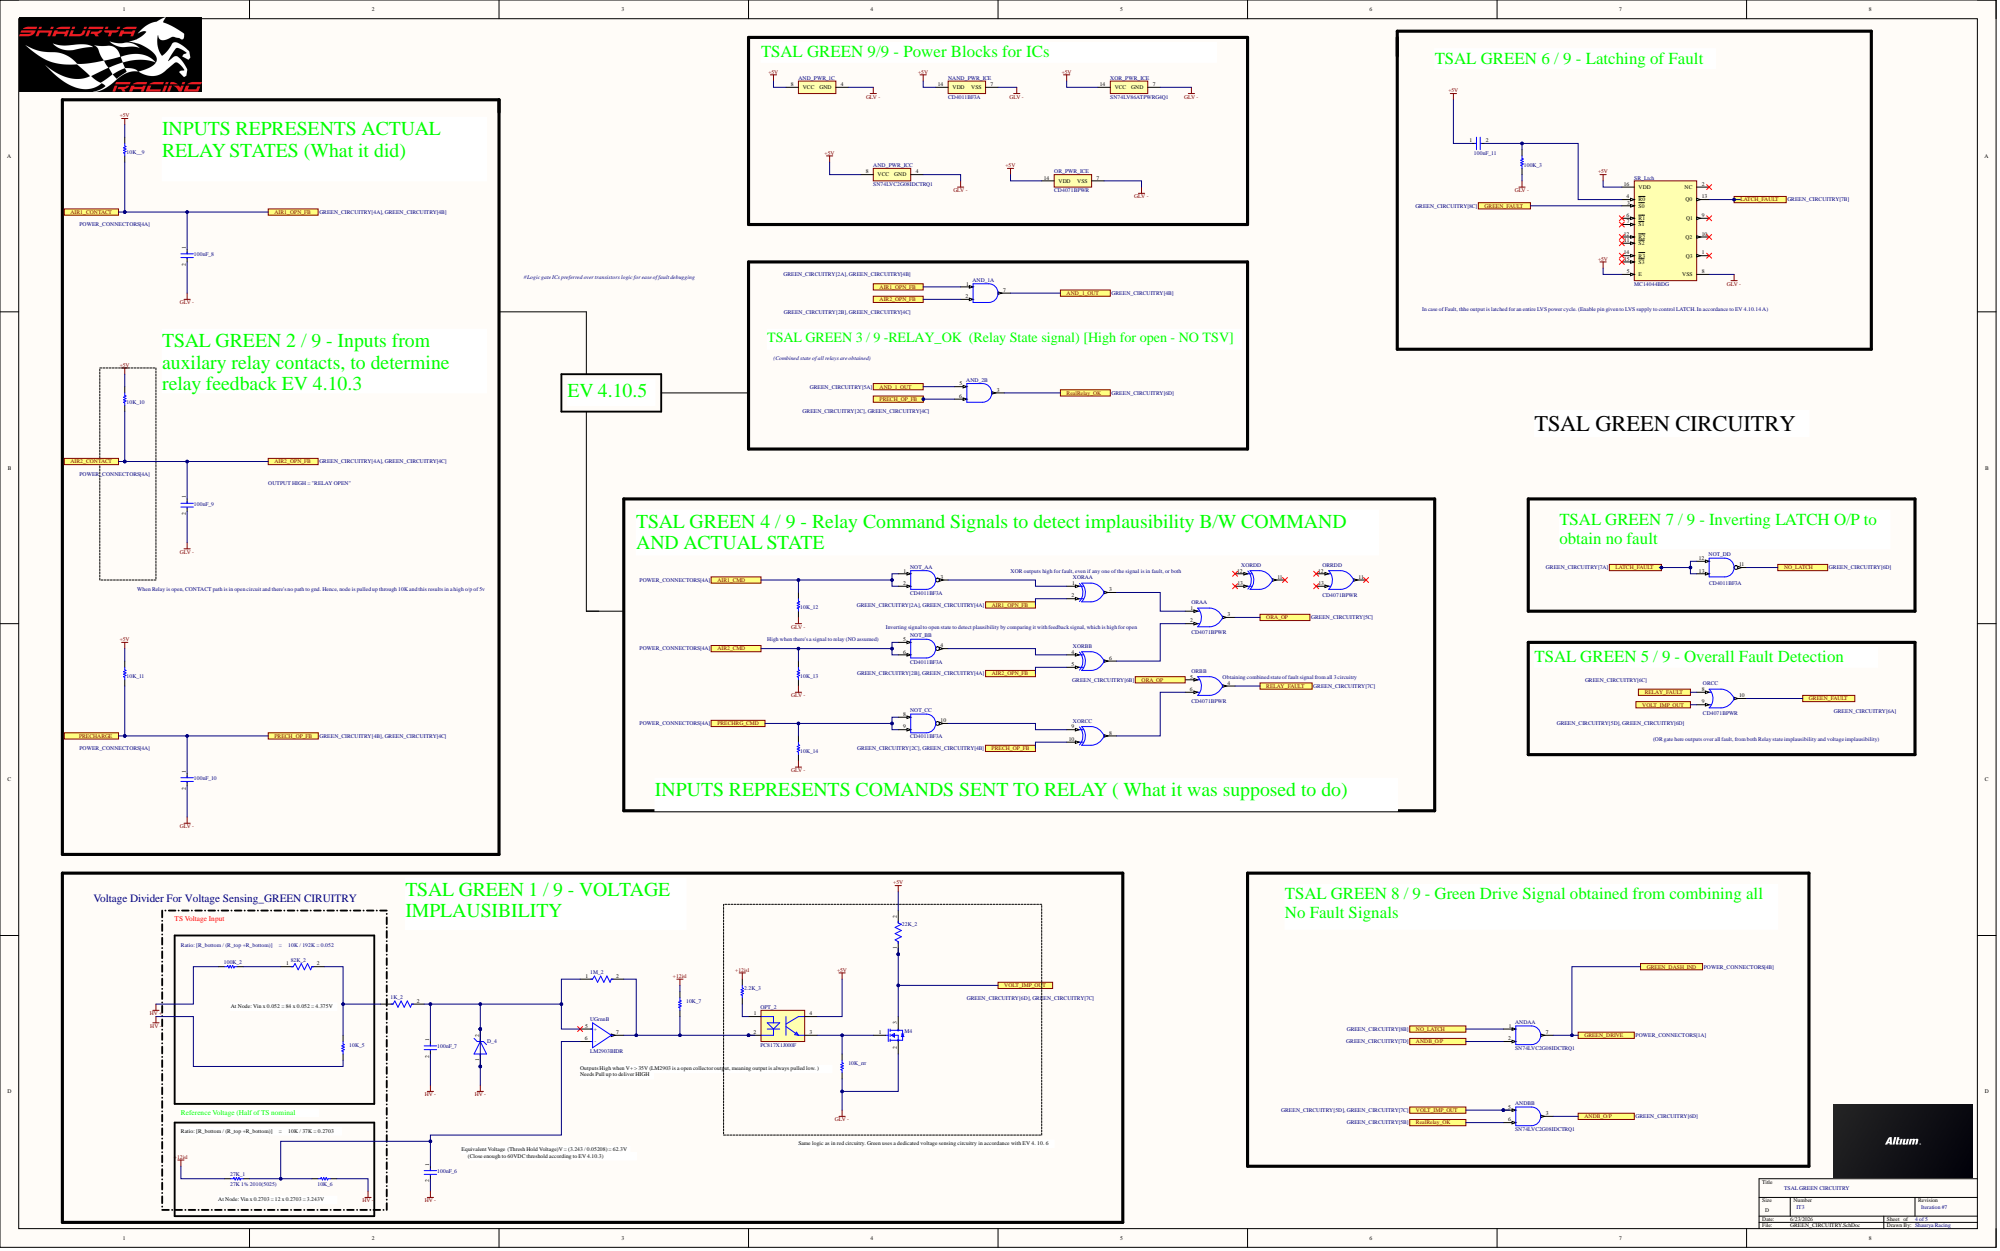
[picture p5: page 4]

TSAL GREEN 9/9 - Power Blocks for ICs

TSAL GREEN 6 / 9 - Latching of Fault

INPUTS REPRESENTS ACTUAL
RELAY STATES (What it did)

#Logic gate ICs preferred overtransistors logic for ease of fault debugging

GLV -
TSAL GREEN 2 / 9 - Inputs from
auxilary relay contacts, to determine
relay feedback EV 4.10.3

In case of Fault, thhe output is latched for an entire LVS power cycle. (Enable pin given to LVS supply to control LATCH. In accordance to EV 4.10.14 A)

GREEN_CIRCUITRY[2B], GREEN_CIRCUITRY[4C]
TSAL GREEN 3 / 9 -RELAY_OK (Relay State signal) [High for open - NO TSV]

(Combined state of all relays are obtained)

OUTPUT HIGH = "RELAY OPEN"

TSAL GREEN 4 / 9 - Relay Command Signals to detect implausibility B/W COMMAND
AND ACTUAL STATE

TSAL GREEN 7 / 9 - Inverting LATCH O/P to
obtain no fault

XOR outputs high for fault, even if any one of the signal is in fault, or both

When Relay is open, CONTACT path is in open circuit and there's no path to gnd. Hence, node is pulled up through 10K and this results in a high o/p of 5v

Inverting signal to open state to detect plausibility by comparing it with feedback signal, which is high for open

High when there's a signal to relay (NO assumed)

TSAL GREEN 5 / 9 - Overall Fault Detection

Obtaining combined state of fault signal from all 3 circuitry

(OR gate here outputs over all fault, from both Relay state implausibility and voltage implausibility)

INPUTS REPRESENTS COMANDS SENT TO RELAY ( What it was supposed to do)

TSAL GREEN 8 / 9 - Green Drive Signal obtained from combining all
No Fault Signals

Voltage Divider For Voltage Sensing_GREEN CIRUITRY

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

Reference Voltage (Half of TS nominal

Same logic as in red circuitry. Green uses a dedicated voltage sensing circuitry in accordance with EV 4. 10. 6

Equivalent Voltage (Thresh Hold Voltage)V = (3.243 / 0.05208) = 62.3V
(Close enough to 60VDC threshold according to EV 4.10.3)

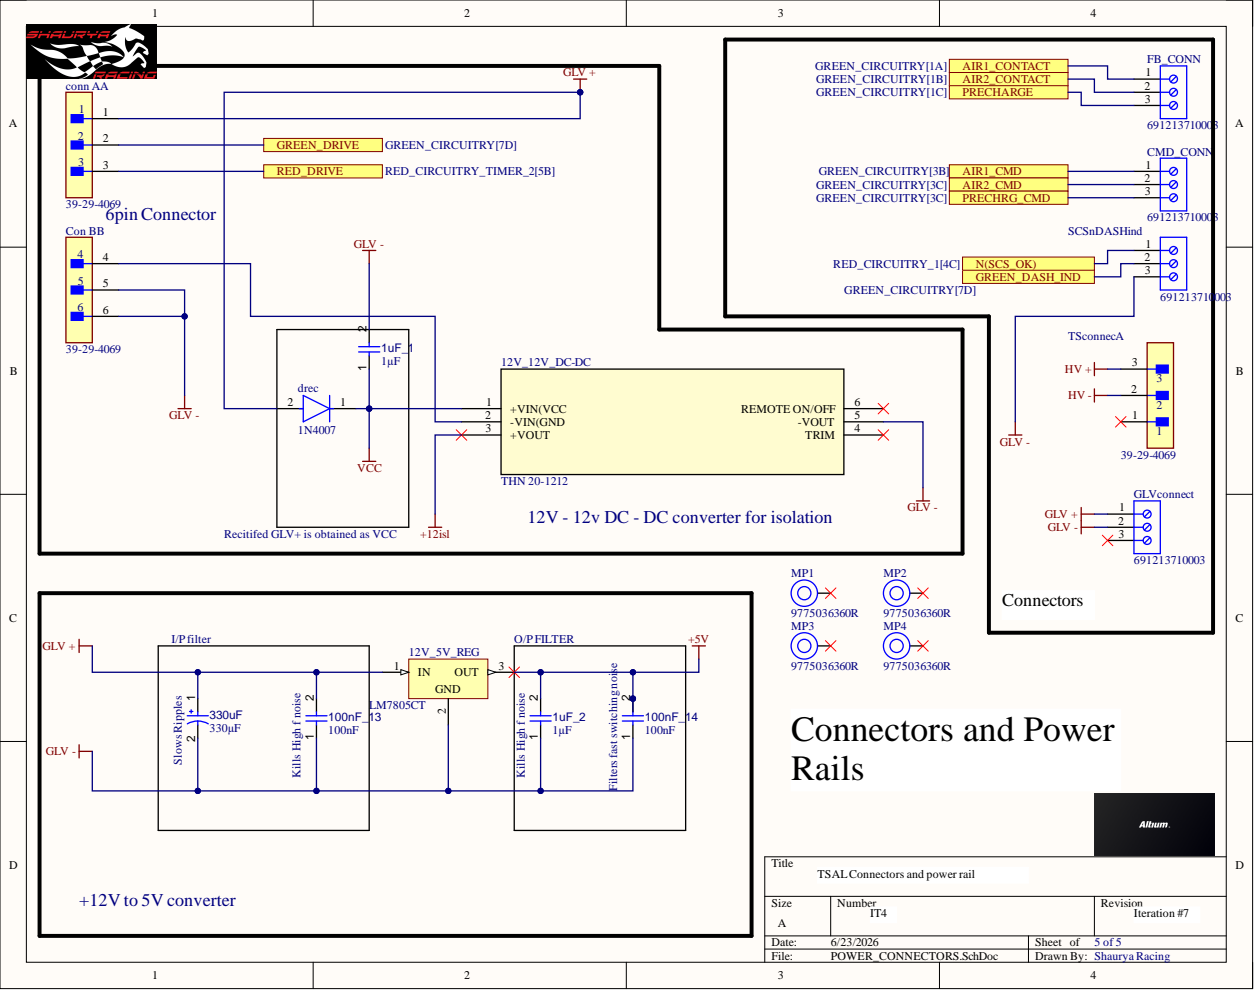
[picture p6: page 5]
File:; POWER_CONNECTORS.SchDoc; Drawn By:; conn AA; Con BB; GLV +; GLV -; +VIN(VCC 1; -VIN(GND 2; +VOUT 3; TRIM; 4 -VOUT; 5 REMOTE ON/OFF; THN 20-1212; 2 OUT 3; +12V to 5V converter; I/P filter; O/P FILTER; 6pin Connector; Connectors and Power; Iteration #7; GLV + GLV -

12V - 12v DC - DC converter for isolation Recitifed GLV+ is obtained as VCC

Filters fast switching noise

Kills High f noise

TSALConnectors and power rail

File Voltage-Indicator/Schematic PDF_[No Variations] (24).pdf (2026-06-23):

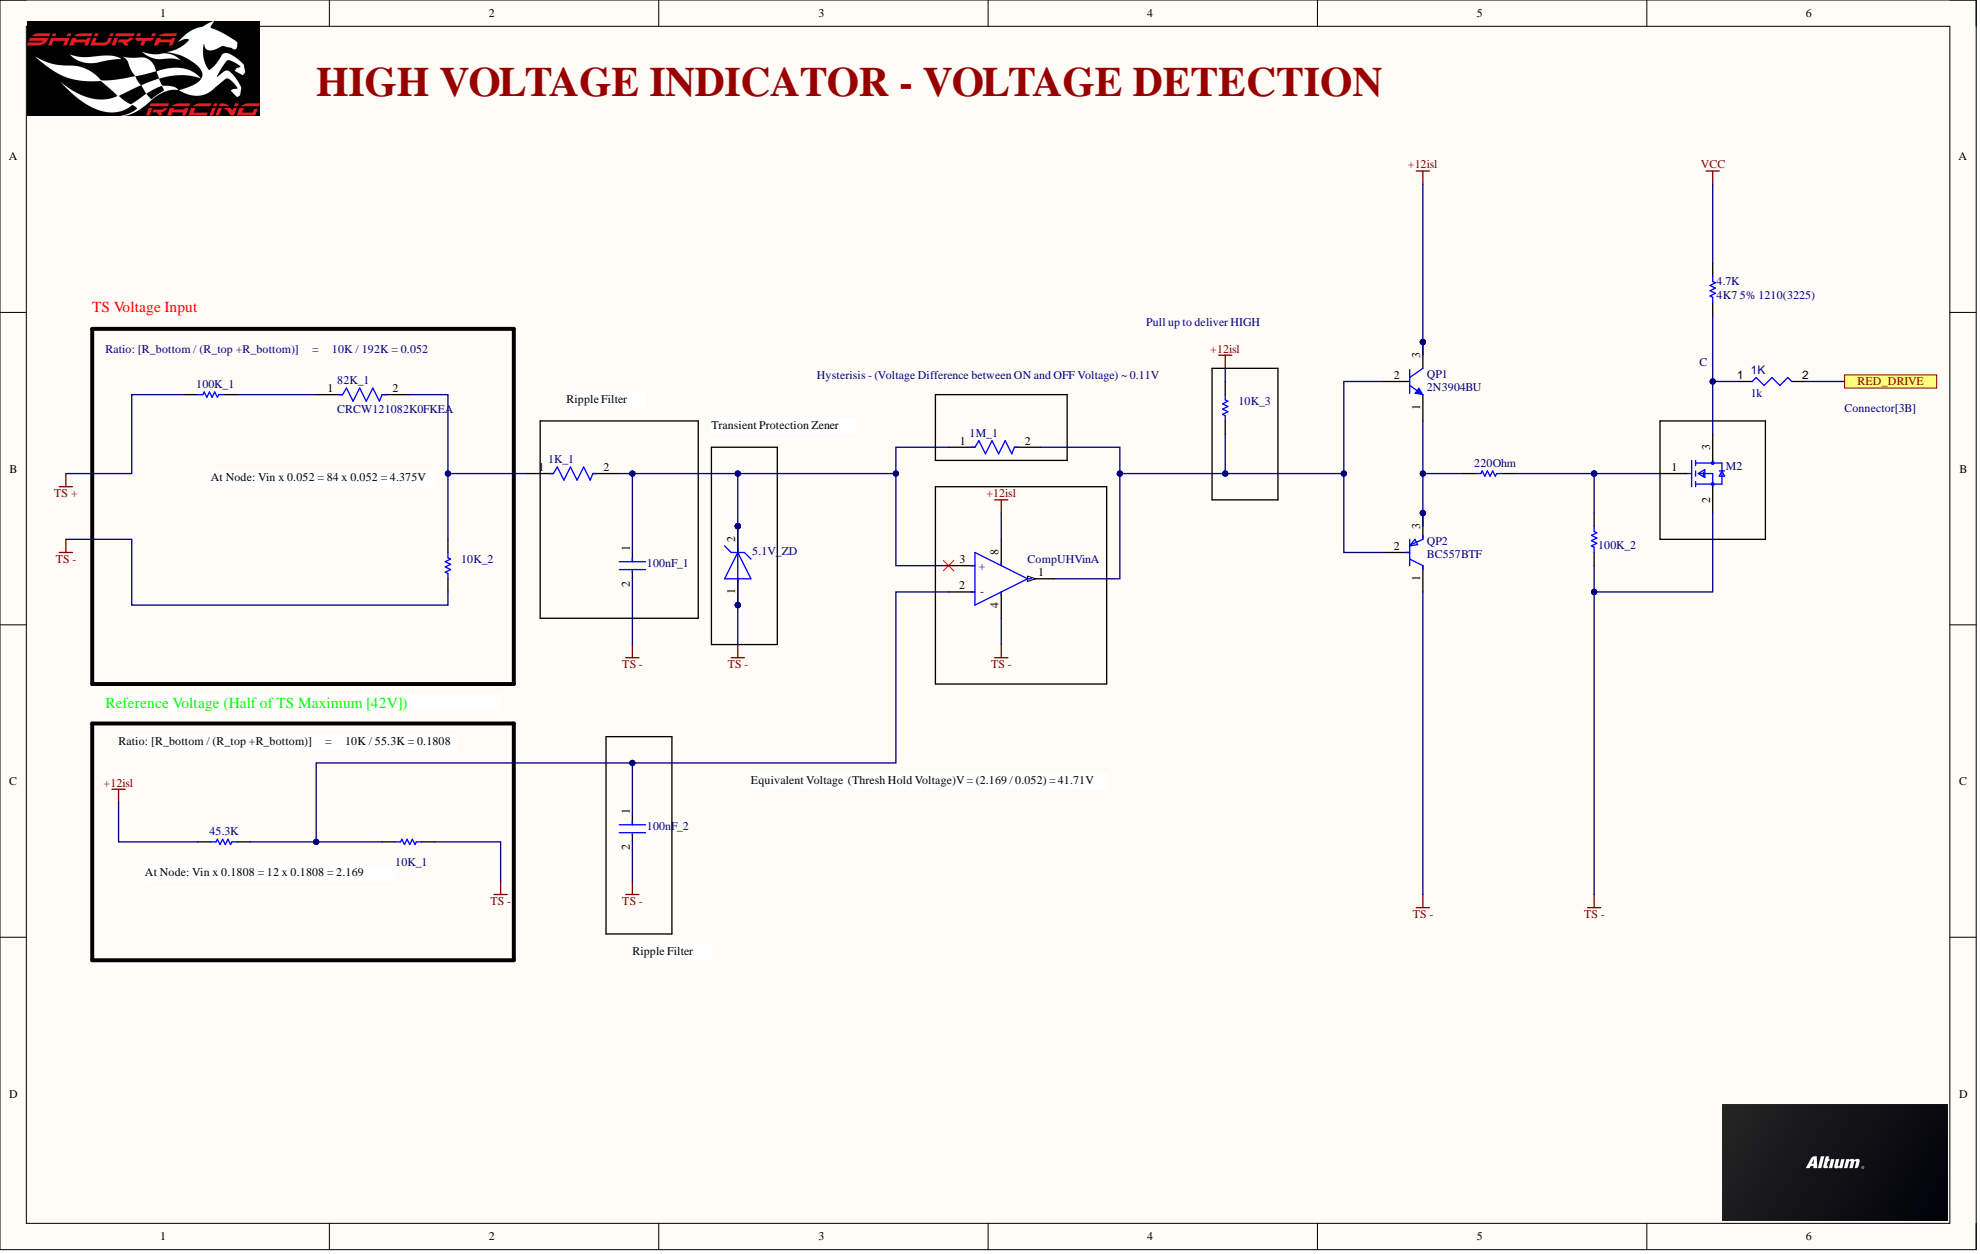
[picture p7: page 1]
e (Half; tage (T; tage)V = (2.1; t Pro; TAGE INDICA; TOR -; TAGE DETECTION

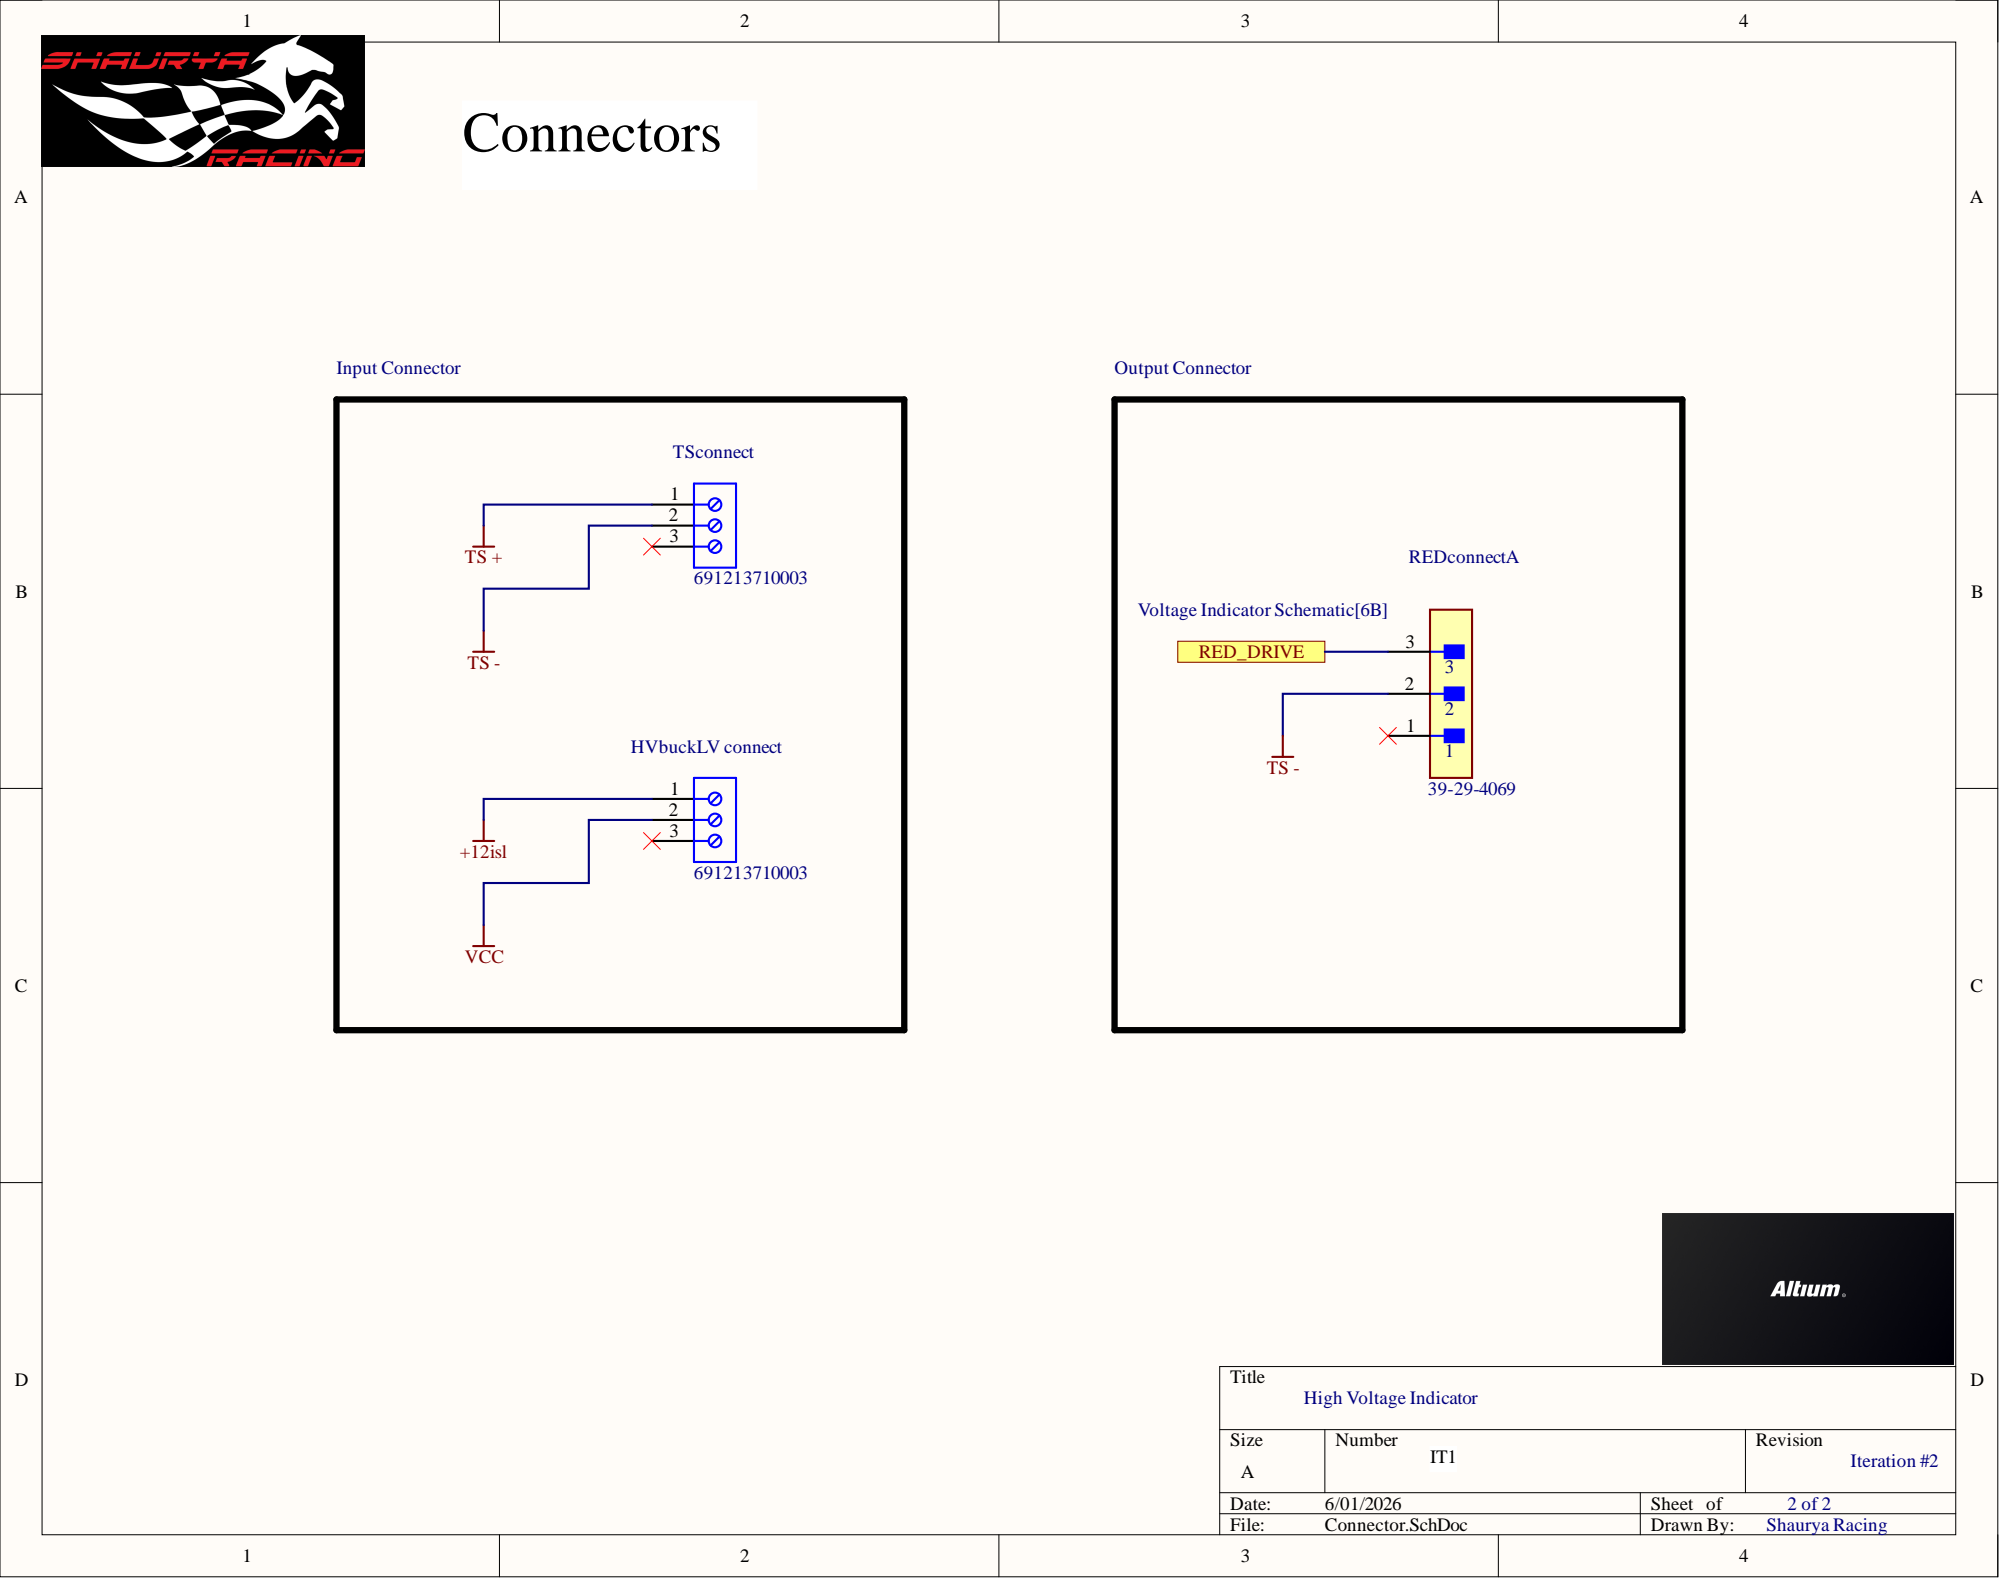
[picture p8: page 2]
Date:; Sheet of; File:; Connector.SchDoc; Drawn By:; HVbuckLV connect; Voltage Indicator Schematic[6B]; Shaurya Racing; Iteration #2; Input Connector; Output Connector; PIHVbuckLV connect01; PIHVbuckLV connect02; PIHVbuckLV connect03; COHVbuckLV connect; PIREDconnect01

High Voltage Indicator

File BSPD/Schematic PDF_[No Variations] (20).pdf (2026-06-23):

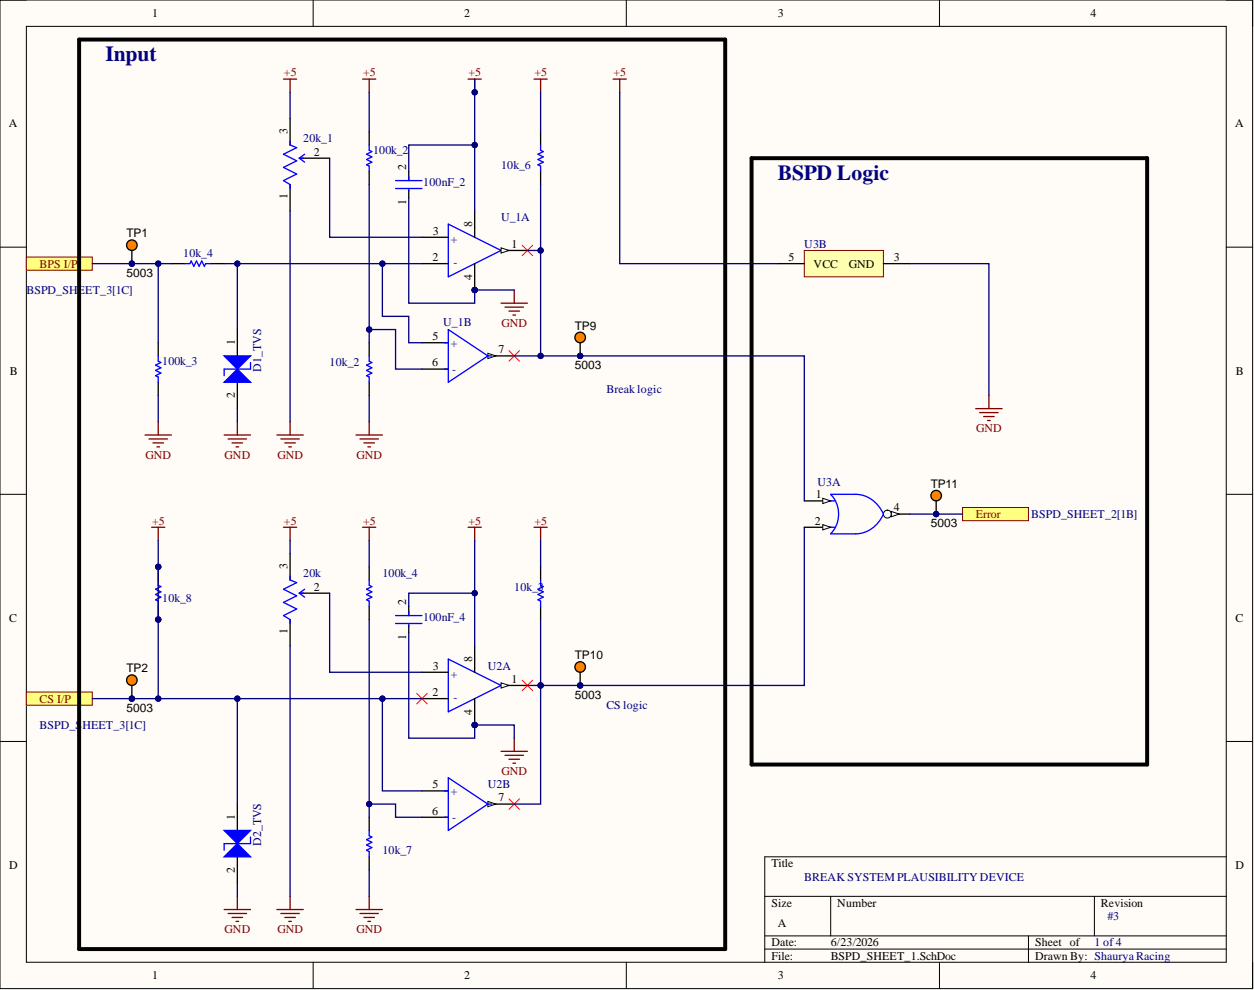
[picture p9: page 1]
+5 GND; Shaurya Raci; K SYST

BSPD Lo gic U 3 B

BPS I/ P

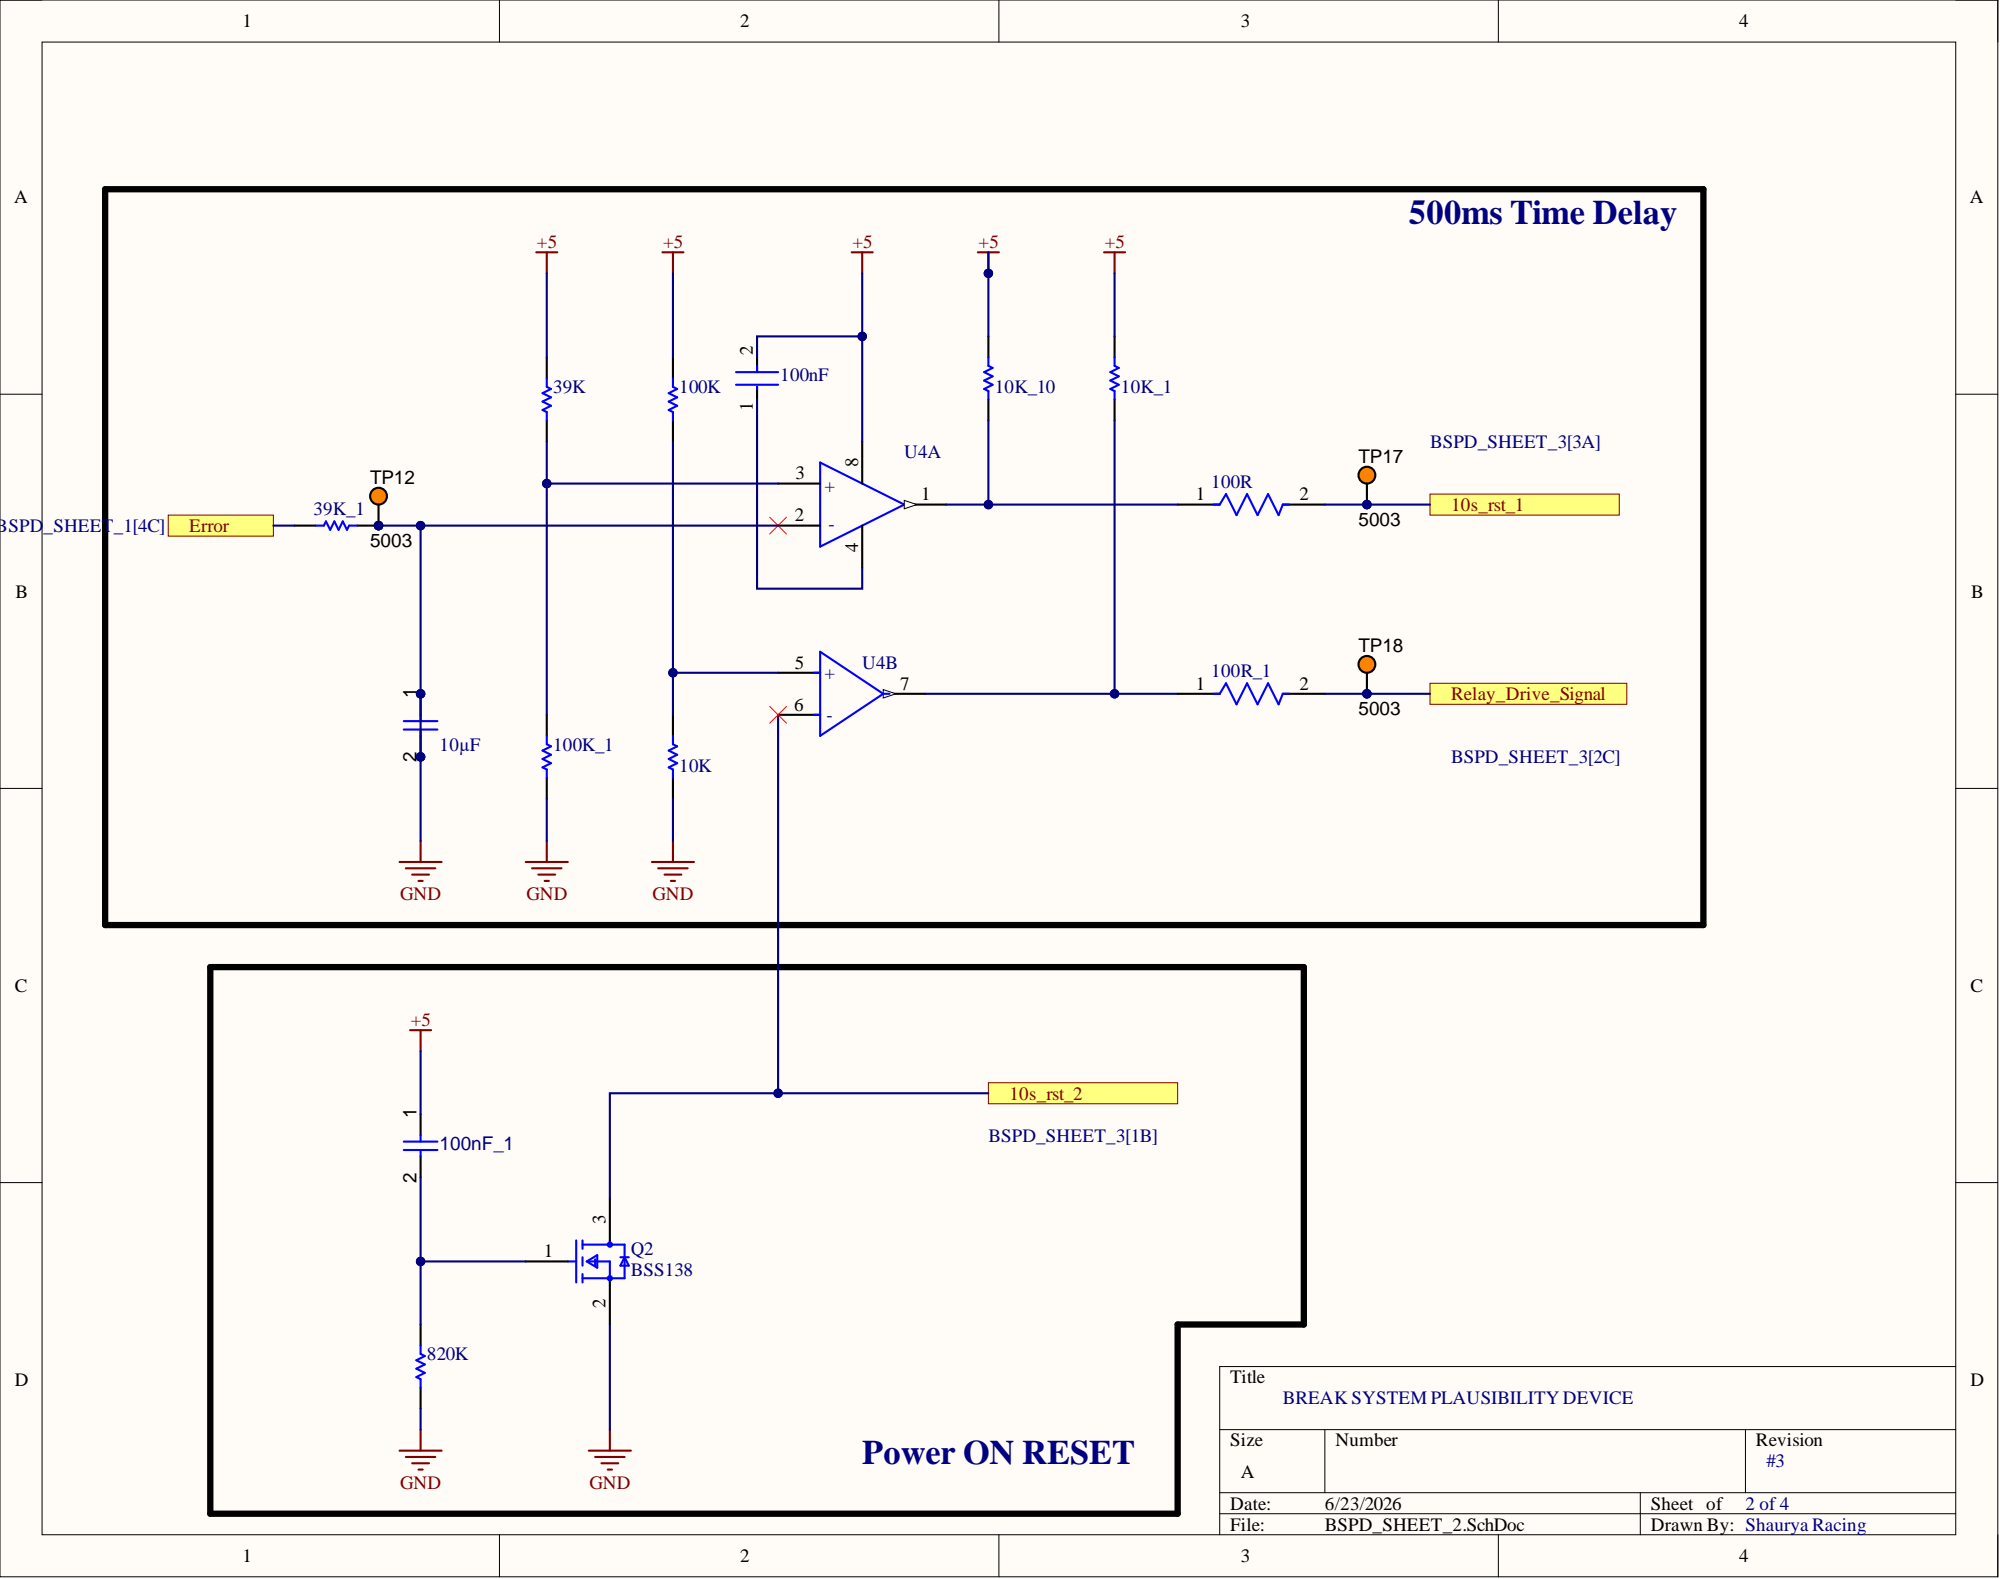
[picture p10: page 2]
Date:; Sheet of; File:; BSPD_SHEET_2.SchDoc; Drawn By:; 500ms Time Delay; Shaurya Racing; PIU408 COU4A

PIU403 | PIU408

PIU402

Title
BREAK SYSTEM PLAUSIBILITY DEVICE

Power ON RESET

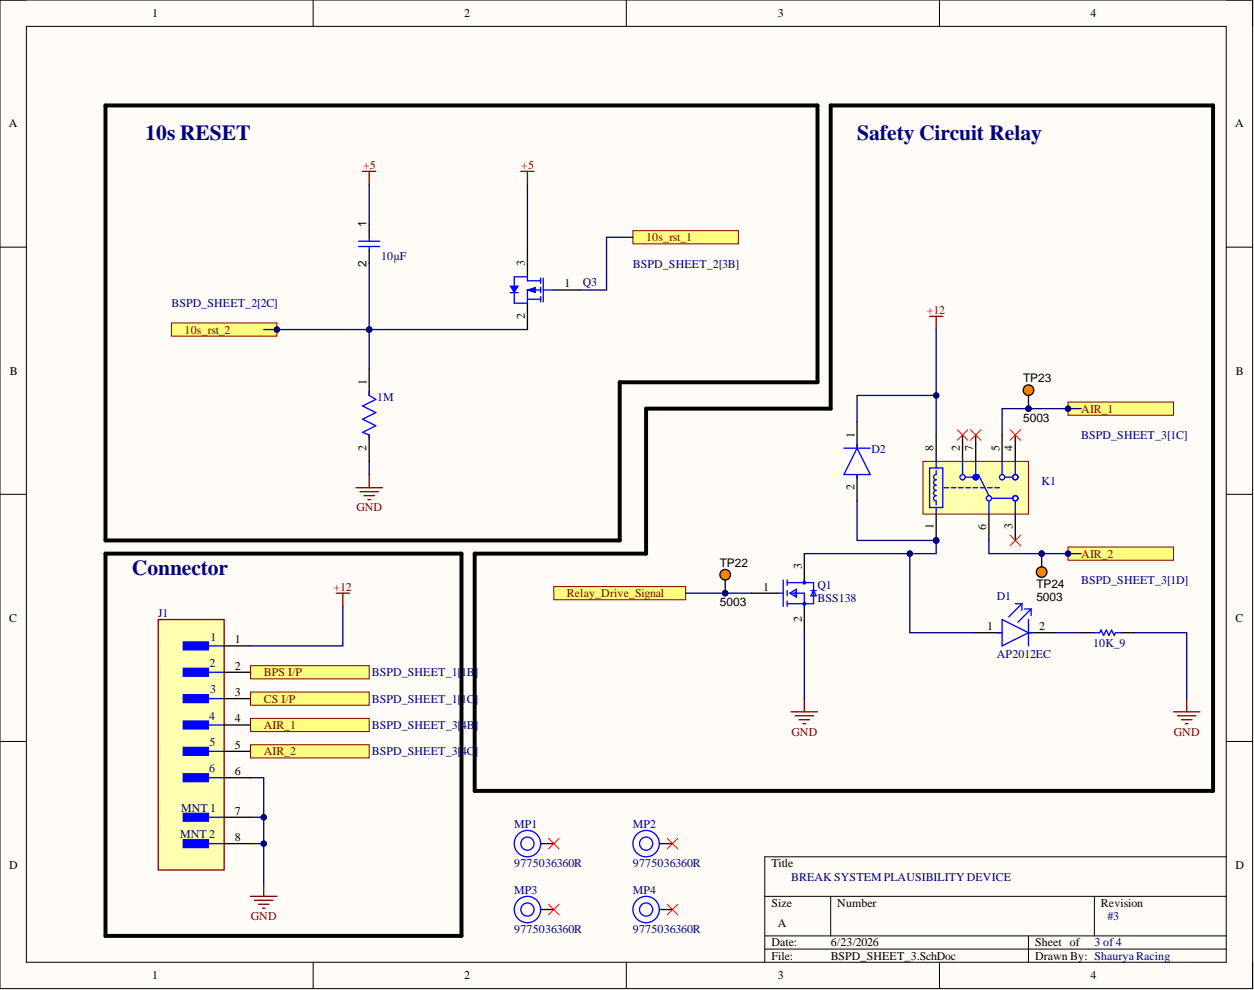
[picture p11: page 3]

Title
BREAK SYSTEM PLAUSIBILITY DEVICE

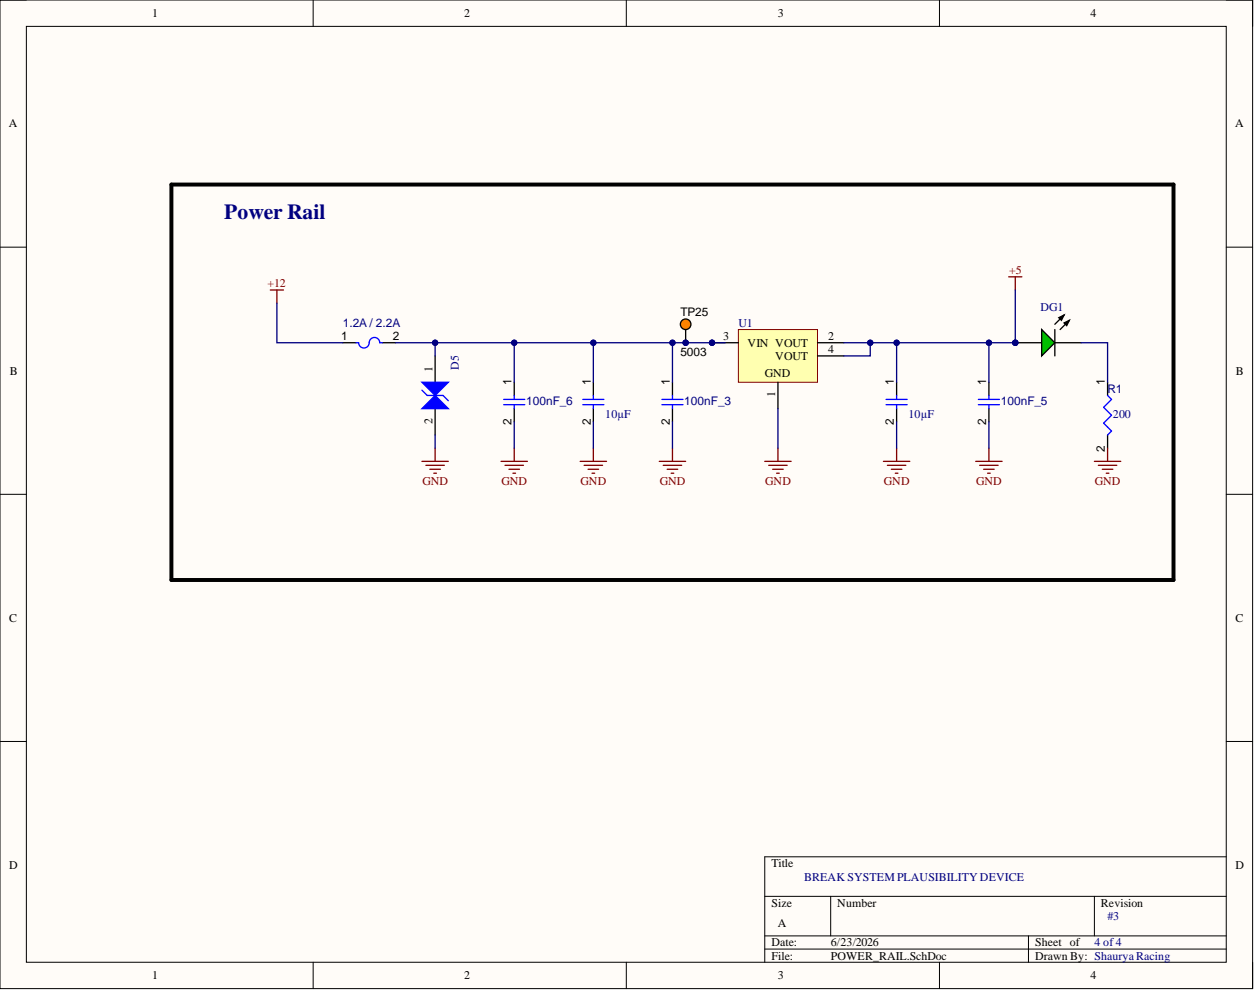
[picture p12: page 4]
Power Rail; K SYST; Shaurya Raci

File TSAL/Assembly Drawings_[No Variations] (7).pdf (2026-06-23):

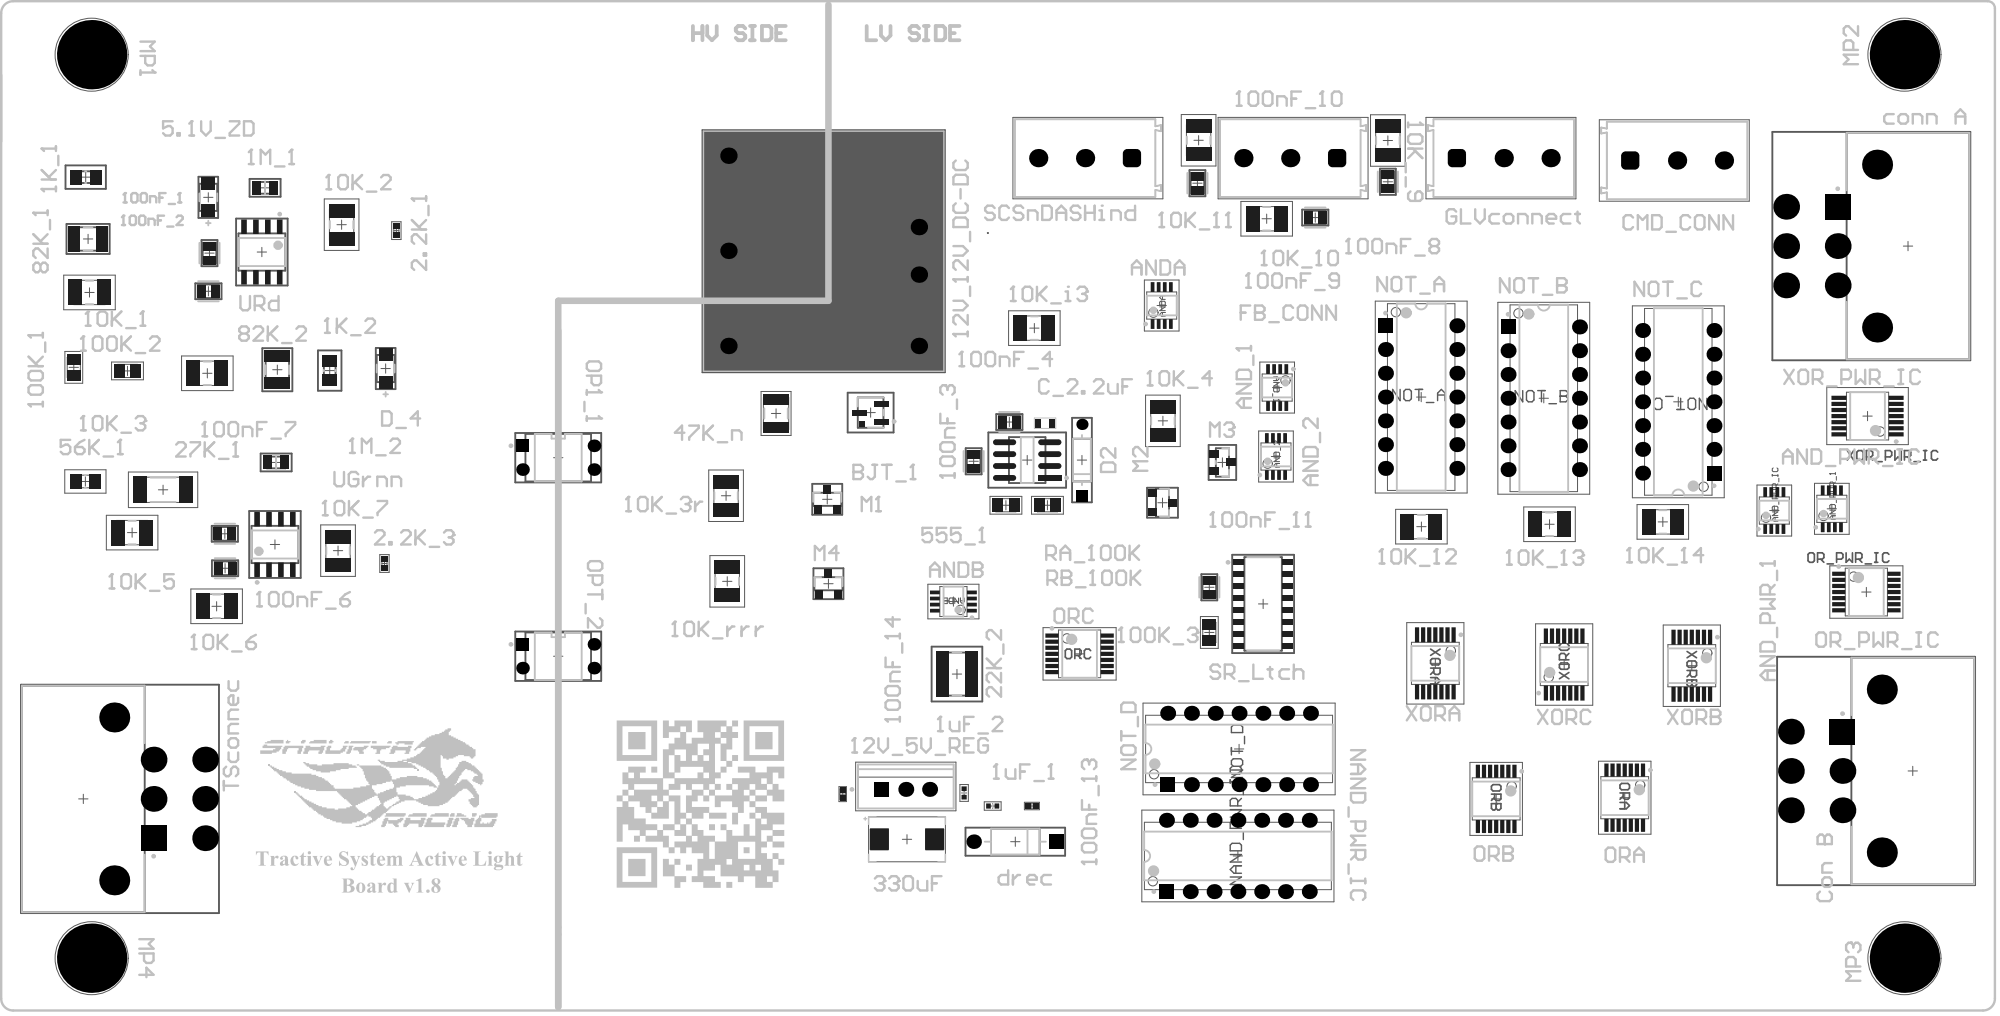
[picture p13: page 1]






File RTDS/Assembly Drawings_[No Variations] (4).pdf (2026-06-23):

PA1K0base01 PA1K0base02; PA1uF0conv01 PA1uF0conv02; CO1uF0conv PA407k01; PA5VREG01; PA5VREG02 PA5VREG03; PAC10100nF01 COC10100nF; PAC201uF01; PA5VREG01 PA100nF02; PASpeakerOutput01 PA1K0base01; PARTDinput02 PA10K02



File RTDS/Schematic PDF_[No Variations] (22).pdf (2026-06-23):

Date:; Sheet of; File:; RTDS_ACTUAL.SchDoc; Drawn By:; VCC 8; PB0(MOSI/DI/SDA/AIN0/OC0A/OC1A/AREF/PCINT0); 3 NPN; GLV +; 2 OUT 3; GLV -; RTDS_ACTUAL[4A]; PI1uF0conv02 CO1uF0conv; PIC10100nF02 COC10100nF PIC201uF01; PIDrect02 CODrect; PINPN01 PINPN02; PINPN03 CONPN; PORTDin PIRTDinput02; PI5VREG02; POPB5 PIInputConnector03; POPB0 PIInputConnector06; POPB1 PIInputConnector05; POPB2 PIInputConnector04; POSpeakerOUT PISpeakerOutput02
